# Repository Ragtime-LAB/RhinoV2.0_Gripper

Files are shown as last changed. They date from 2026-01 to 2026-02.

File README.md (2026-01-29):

# RhinoV2.0 自适应夹爪 / Adaptive Gripper



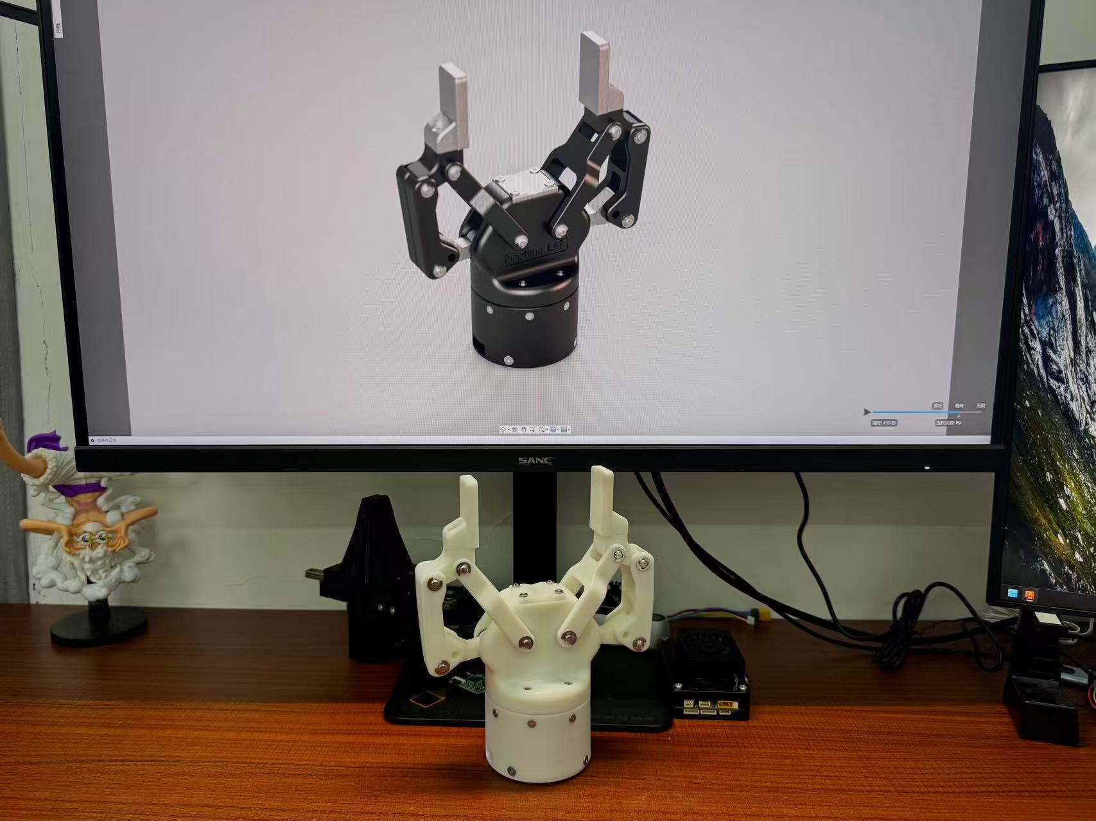
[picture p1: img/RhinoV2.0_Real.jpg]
RhinoV2.0 实物图


 

---

### 📖 项目简介

RhinoV2.0 是一款开源的自适应两指夹爪，设计灵感来源于 Robotiq 2F-85 商用夹爪。本项目旨在提供一款低成本、高性能、易于制造和组装的机械夹爪解决方案，让更多机器人爱好者、学生和个人开发者能够用上经济实惠的末端执行器。

> 💰 **成本优势**：采用 3D 打印方式制作，整套成本不超过 ¥1000，远低于商业夹爪价格！

### 🎯 项目初衷

- **降低门槛**：商业夹爪价格高昂（如 Robotiq 2F-85 售价约 ¥14,000+），我们希望让更多人用得起
- **开源共享**：所有设计文件完全开源，支持自由修改和优化
- **教育价值**：为机械工程、机器人专业的同学提供学习和参考的设计案例
- **可制造性**：采用标准件+通用加工工艺，降低制造成本
- **可扩展性**：设计模块化，便于二次开发和改进

### ✨ 主要特点

- 💰 **超低成本**：3D 打印版本整套成本 < ¥1000
- 自适应夹持，可兼容不同形状和尺寸的物体
- 欠驱动机构设计，结构紧凑
- 采用关节电机（达妙 DM4310）驱动
- 支持 FDM 3D打印或 CNC 加工
- 完整的 SolidWorks 源文件和 STEP 通用格式

### 📁 文件结构

```
RhinoV2.0_Gripper/
├── 0_Solidworks2025/          # SolidWorks 2025 源文件
│   ├── RhinoV2.0_Assembly.SLDASM   # 总装配体
│   ├── DM4310.SLDPRT               # 关节电机模型
│   └── ...                         # 所有零件模型
│
├── 1_STEP/                         # STEP 通用格式文件
│   └── RhinoV2.0_Assembly.STEP     # 完整装配体 STEP 文件
│
├── 2_Bom/                          # 物料清单与加工文件
│   ├── BOM.xlsx                    # 总物料清单
│   ├── FDM或CNC/                   # 可3D打印或 CNC 的零件
│   ├── 嘉立创钣金304或铨洲/          # 钣金件或CNC加工文件
│   ├── 铨洲三轴CNC/                 # CNC 加工文件
│   └── 丝杆及螺母/                  # 丝杆组件相关
│
├── 3_RhinoV2.0_Gripper_control/   # 夹爪控制系统代码
│   ├── gripper_ui_integrated.py    # 整合控制UI（推荐）
│   ├── motor_control_pyqt.py       # 手动控制程序
│   ├── damiao.py                   # 达妙电机控制库
│   ├── test_pressure.py            # 压力传感器测试
│   ├── requirements.txt            # Python依赖
│   └── README.md                   # 控制系统详细文档
│
├── img/                            # 项目图片
│   └── RhinoV2.0_Real.jpg          # 实物图
│
├── README.md                  # 本文件
└── LICENSE                    # GPL-3.0 开源许可证
```

### ⚙️ 硬件配置

| 项目 | 参数 |
|---|---|
| 驱动电机 | 达妙 DM4310 关节电机 |
| 夹持行程 | (待补充) |
| 最大夹持力 | (待补充) |
| 重量 | (待补充) |
| 加工方式 | FDM 3D打印 / CNC / 钣金 |

### 🚀 快速开始

#### 1. 📄 获取设计文件

- **SolidWorks 用户**：直接使用 `0_Solidworks2025/` 中的源文件进行修改
- **其他 CAD 软件**：导入 `1_STEP/RhinoV2.0_Assembly.STEP` 文件

#### 2. 🔧 零件加工

参考 `2_Bom/` 目录下的详细清单：
- 可 3D 打印零件列表
- CNC 加工图纸
- 钣金件加工文件
- 标准件采购清单（轴承、螺丝等）

> 💡 **学生党福利**：如果您觉得结构件或丝杆价格昂贵，欢迎联系我们组织拼单购买，多人一起可以降低成本！

#### 3. 🔨 组装

(详细的组装教程视频/文档即将推出)

### 🤝 贡献指南

我们欢迎任何形式的贡献：

- 🐛 报告 Bug
- 💡 提出新功能建议
- 🎨 提交设计改进
- 📝 完善文档
- 📸 分享您的制作成果

**有意向加入团队？**

如果您对这个项目充满热情，希望加入我们的团队一起开发更好的夹爪，欢迎通过上述联系方式（邮箱或微信）与我们联系！我们期待您的加入！

### ⚖️ 许可证

本项目采用 [GPL-3.0 License](LICENSE) 开源协议，主要特点：

- ✅ **允许商业使用**：您可以自由地将本项目用于商业目的
- ✅ **要求开源**：如果您基于本项目修改或衍生出新作品，必须同样以 GPL-3.0 协议开源
- ✅ **专利保护**：GPL-3.0 提供明确的专利授权保护，防止专利诉讼
- ✅ **自由使用**：您可以自由使用、修改和分发本项目

> 💡 **简单来说**：您可以商用、可以修改，但修改后的代码也必须开源！

### 🙏 致谢

- 设计灵感来源于 [Robotiq 2F-85](https://robotiq.com/products/2f85-140-adaptive-robot-gripper)
- 感谢所有为本项目做出贡献的开发者

**特别鸣谢 / Special Thanks**

- **小一** - 感谢您的赞助支持 | GitHub: [KelvinLauMiau](https://github.com/KelvinLauMiau)
贡献：为结构提出大部分思路以及外观优化以及所有研发费用的支出
- **乐乐汉堡** - 感谢您的激励和指导 | Bilibili: [乐乐汉堡](https://space.bilibili.com/435723766?spm_id_from=333.337.0.0)
贡献：作为作者的学习的榜样，并提出关键指导

### 📧 联系方式

- 👤 作者：wEch1ng（芝士榴莲肥牛）
- 🔗 前代项目：[RhinoV1.0_Gripper](https://github.com/wEch1ng/Rhino_Gripper)
- 📧 邮箱：3575868884@qq.com
- 💬 微信：xwccc12028
- 🤝 如有问题或合作意向，欢迎联系！

---

**如果这个项目对您有帮助，请给一个 Star ⭐**

---

**[回到顶部](#rhinov20-自适应夹爪)**

---



RhinoV2.0 实物图

 

---

### 📖 Introduction

RhinoV2.0 is an open-source adaptive two-finger gripper, inspired by the commercial Robotiq 2F-85 gripper. This project aims to provide a low-cost, high-performance, and easy-to-manufacture robotic gripper solution, making end-effectors accessible to more robotics enthusiasts, students, and individual developers.

> 💰 **Cost Advantage**: With 3D printing, the complete set costs less than $200, far below commercial gripper prices!

### 🎯 Project Motivation

- **Accessibility**: Commercial grippers are expensive (e.g., Robotiq 2F-85 costs around $2000+), we aim to make them affordable
- **Open Source**: All design files are fully open-source, supporting free modification and optimization
- **Educational Value**: Provides design references for mechanical engineering and robotics students
- **Manufacturability**: Uses standard parts and common manufacturing processes to reduce cost
- **Extensibility**: Modular design facilitates secondary development and improvements

### ✨ Key Features

- 💰 **Ultra-low Cost**: 3D printed version complete set < $200
- Adaptive gripping compatible with objects of various shapes and sizes
- Underactuated mechanism design with compact structure
- Joint motor (DAMIAO DM4310) driven
- Supports FDM 3D printing or CNC machining
- Complete SolidWorks source files and STEP universal format

### 📁 File Structure

```
RhinoV2.0_Gripper/
├── 0_Solidworks2025/          # SolidWorks 2025 source files
│   ├── RhinoV2.0_Assembly.SLDASM   # Main assembly
│   ├── DM4310.SLDPRT              # Joint motor model
│   └── ...                        # All part models
│
├── 1_STEP/                    # STEP universal format files
│   └── RhinoV2.0_Assembly.STEP    # Complete assembly STEP file
│
├── 2_Bom/                     # Bill of materials and manufacturing files
│   ├── BOM.xlsx                    # Total BOM list
│   ├── FDM或CNC/                   # FDM 3D printing or CNC parts
│   ├── 嘉立创钣金304或铨洲/         # Sheet metal fabrication or CNC files
│   ├── 铨洲三轴CNC/                 # CNC machining files
│   └── 丝杆及螺母/                  # Lead screw assembly related
│
├── 3_RhinoV2.0_Gripper_control/   # Gripper control system code
│   ├── gripper_ui_integrated.py    # Integrated control UI (recommended)
│   ├── motor_control_pyqt.py       # Manual control program
│   ├── damiao.py                   # DAMIAO motor control library
│   ├── test_pressure.py            # Pressure sensor test
│   ├── requirements.txt            # Python dependencies
│   └── README.md                   # Control system documentation
│
├── img/                       # Project images
│   └── RhinoV2.0_Real.jpg          # Photo of real product
│
├── README.md                  # This file
└── LICENSE                    # GPL-3.0 open source license
```

### ⚙️ Hardware Specifications

| Item | Specification |
|---|---|
| Motor | DAMIAO DM4310 Joint Motor |
| Gripping Stroke | (TBD) |
| Max Gripping Force | (TBD) |
| Weight | (TBD) |
| Manufacturing | FDM 3D printing / CNC / Sheet metal |

### 🚀 Quick Start

#### 1. 📄 Obtain Design Files

- **For SolidWorks Users**: Use source files in `0_Solidworks2025/` directly for modification
- **For Other CAD Software**: Import `1_STEP/RhinoV2.0_Assembly.STEP` file

#### 2. 🔧 Parts Manufacturing

Refer to detailed lists in `2_Bom/` directory:
- 3D printable parts list
- CNC machining drawings
- Sheet metal fabrication files
- Standard parts procurement list (bearings, screws, etc.)

> 💡 **For Students**: If you find structural parts or lead screws expensive, feel free to contact us to organize group purchases. Buying together can reduce costs significantly!

#### 3. 🔨 Assembly

(Detailed assembly tutorial video/documentation coming soon)

### 🤝 Contributing

We welcome contributions in any form:

- 🐛 Bug reports
- 💡 Feature requests
- 🎨 Design improvements
- 📝 Documentation enhancements
- 📸 Share your build

**Interested in Joining the Team?**

If you are passionate about this project and want to join our team to develop better grippers together, please feel free to contact us via email or WeChat listed above. We look forward to having you!

### ⚖️ License

This project is licensed under the [GPL-3.0 License](LICENSE). Key features:

- ✅ **Commercial Use Allowed**: You are free to use this project for commercial purposes
- ✅ **Copyleft Required**: If you modify or create derivative works based on this project, you must release them under GPL-3.0 as well
- ✅ **Patent Protection**: GPL-3.0 provides explicit patent license protection to prevent patent litigation
- ✅ **Freedom to Use**: You are free to use, modify, and distribute this project

> 💡 **In Short**: Commercial use is allowed, modifications are allowed, but modified code must also be open source!

### 🙏 Acknowledgments

- Design inspired by [Robotiq 2F-85](https://robotiq.com/products/2f85-140-adaptive-robot-gripper)
- Thanks to all developers who contributed to this project

**Special Thanks**

- **小一 (Xiao Yi)** - Thank you for your sponsorship | GitHub: [KelvinLauMiau](https://github.com/KelvinLauMiau)
  - Contribution: Proposed most of the structural design concepts, appearance optimization, and covered all R&D expenses
- **乐乐汉堡 (Lele Hamburger)** - Thank you for your motivation and guidance | Bilibili: [乐乐汉堡](https://space.bilibili.com/435723766?spm_id_from=333.337.0.0)
  - Contribution: Served as the author's role model and provided key guidance

### 📧 Contact

- 👤 Author: wEch1ng（芝士榴莲肥牛）
- 🔗 Previous Project: [RhinoV1.0_Gripper](https://github.com/wEch1ng/Rhino_Gripper) 
- 📧 Email: 3575868884@qq.com
- 💬 WeChat: xwccc12028
- 🤝 Feel free to contact for any questions or collaboration!

---

**If this project helps you, please give it a Star ⭐**

---

**[Back to Top](#rhinov20-自适应夹爪)**

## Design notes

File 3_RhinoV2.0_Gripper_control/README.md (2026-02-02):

# RhinoV2.0 夹爪控制系统

本项目是基于达妙电机和压力传感器的智能夹爪控制系统，支持手动控制和PID闭环控制两种模式。

---

## 目录

- [硬件清单](#硬件清单)
- [环境安装](#环境安装)
- [快速开始](#快速开始)
- [文件结构](#文件结构)
- [主要程序说明](#主要程序说明)
- [配置说明](#配置说明)
- [常见问题](#常见问题)
- [开发说明](#开发说明)
- [安全注意事项](#安全注意事项)

---

## 硬件清单

### 必需硬件

#### 1. 达妙电机
- **型号**：DM4310（或 DM4340、DM6006 等）
- **额定力矩**：4.3 N·m (DM4310)
- **控制模式**：MIT模式、位置速度模式、速度模式
- **通信接口**：CAN总线
- **供电**：24V DC
- **厂商**：达妙科技
- **用途**：夹爪驱动执行器

#### 2. USB-CAN适配器
- **型号**：DM-FDCAN
- **接口**：USB 2.0
- **CAN协议**：CAN 2.0 / CAN-FD
- **波特率**：可配置（默认 1Mbps）
- **厂商**：达妙科技
- **用途**：电脑与电机CAN总线通信

#### 3. 6x6阵列压力传感器（仅作参考）
- **型号**：6x6阵列压力传感器（36点）
- **厂商**：深圳力感科技
- **类型**：电阻式力敏触觉传感器 (FSR)
- **阵列规格**：6×6 = 36个传感点
- **单点尺寸**：2.5mm × 2.5mm
- **单点面积**：6.25 mm²
- **通信接口**：串口 (UART)
- **波特率**：460800
- **数据格式**：自定义协议（帧头 0xFF66，78字节/帧）
- **应用场景**：机器人手指抓握力识别、触觉反馈
- **购买链接**：
【淘宝】退货运费险 https://e.tb.cn/h.7qFeOVKt2sKIyvf?tk=kPtyU7QJ8po MF937 「原厂人形机器人手指识别抓握力大小电阻式力敏多点触觉传感器FSR」
点击链接直接打开 或者 淘宝搜索直接打开

### 可选硬件

- **电源**：24V DC电源适配器（电机供电）
- **CAN终端电阻**：120Ω（CAN总线两端）
- **连接线缆**：
  - USB数据线（连接USB-CAN适配器）
  - CAN总线线缆
  - 串口线（连接压力传感器）

### 硬件连接示意

```
电脑 ──USB── USB-CAN适配器 ──CAN总线── 达妙电机
 │
 └──串口── 压力传感器
```

---

## 环境安装

### 系统要求

- **操作系统**：Linux (推荐 Ubuntu 18.04+)
- **Python 版本**：Python 3.8+
- **硬件要求**：
  - USB-CAN适配器（达妙 DM-FDCAN）
  - 达妙电机（DM4310 或其他型号）
  - 6x6阵列压力传感器（深圳力感科技）

### 安装步骤

#### 1. 克隆或下载项目

```bash
cd /home/wech1ng/Project/
# 如果已有项目，跳过此步
```

#### 2. 安装Python依赖

```bash
cd RhinoV2.0_Gripper_control

# 方法1：使用 requirements.txt（推荐）
pip3 install -r requirements.txt

# 方法2：手动安装
pip3 install PyQt5>=5.15.0
pip3 install numpy>=1.19.0
pip3 install matplotlib>=3.3.0
pip3 install pyserial>=3.5
pip3 install pyusb>=1.2.0
```

#### 3. 配置USB设备权限

```bash
# 添加当前用户到 dialout 组（串口权限）
sudo usermod -a -G dialout $USER

# 设置USB设备权限（USB-CAN适配器）
sudo chmod 666 /dev/bus/usb/*/*

# 注意：需要重新登录或重启才能生效
```

#### 4. 验证安装

```bash
# 检查Python版本
python3 --version

# 检查依赖库
python3 -c "import PyQt5, numpy, matplotlib, serial, usb; print('所有依赖库已安装')"

# 检查USB-CAN设备
python3 dev_sn.py
```

**预期输出：**
```
Found DM-FDCAN, device-id: device:3,21 SN: 818F9E6ACF42F4147B2EE0FE9382AF11
```

---

## 快速开始

### 1. 硬件连接

#### 电机连接
1. 连接USB-CAN适配器到电脑USB口
2. 连接达妙电机到CAN总线
3. 确保电机供电正常（24V）

#### 传感器连接
1. 连接压力传感器到串口（通常是 `/dev/ttyUSB1` 或 `/dev/ttyACM0`）
2. 确认波特率为 460800

**传感器规格：**
- **型号**：6x6阵列压力传感器（36点）
- **厂商**：深圳力感科技
- **类型**：电阻式力敏触觉传感器 (FSR)
- **单点尺寸**：2.5mm × 2.5mm
- **通信接口**：串口 (UART)
- **波特率**：460800
- **应用场景**：机器人手指抓握力识别、触觉反馈

> **购买参考**：淘宝搜索"人形机器人手指识别抓握力大小电阻式力敏多点触觉传感器FSR"

### 2. 读取设备序列号（重要）

每个USB-CAN适配器都有唯一的设备序列号（SN），需要先读取并配置到程序中。

```bash
# 运行设备序列号读取工具
python3 dev_sn.py
```

**输出示例：**
```
Found DM-FDCAN, device-id: device:3,21 SN: 818F9E6ACF42F4147B2EE0FE9382AF11
```

记录下这个 **SN码**：`818F9E6ACF42F4147B2EE0FE9382AF11`

### 3. 修改程序中的设备码

找到程序中的这一行（通常在主函数或初始化部分）：

```python
self.control = Motor_Control(1000000, 5000000,
                            "818F9E6ACF42F4147B2EE0FE9382AF11",  # ← 修改这里
                            init_data)
```

**将SN码替换为你的设备码。**

#### 需要修改的文件：

1. **gripper_ui_integrated.py**（推荐使用）
   - 位置：`init_hardware()` 函数中，约第667行
   - 搜索：`Motor_Control(1000000, 5000000,`

2. **motor_control_pyqt.py**
   - 位置：`init_motor()` 函数中，约第295行

3. **gripper_control_with_visualization.py**
   - 位置：`if __name__ == "__main__":` 部分

#### 修改示例：

**修改前：**
```python
with Motor_Control(1000000, 5000000, "818F9E6ACF42F4147B2EE0FE9382AF11", init_data1) as control:
```

**修改后（假设你的SN是 `AA96DF2EC013B46B1BE4613798544085`）：**
```python
with Motor_Control(1000000, 5000000, "AA96DF2EC013B46B1BE4613798544085", init_data1) as control:
```

### 4. 检查串口设备

```bash
# 查看可用串口
ls -l /dev/ttyUSB* /dev/ttyACM*
```

**输出示例：**
```
/dev/ttyUSB1  # 压力传感器
/dev/ttyACM0  # 其他设备
```

如果传感器不在 `/dev/ttyUSB1`，需要修改程序中的串口配置：

```python
# 在程序开头找到这一行（约第33行）
SERIAL_PORT = '/dev/ttyUSB1'  # 修改为实际串口
```

### 5. 运行程序

#### 推荐：使用整合UI程序

```bash
python3 gripper_ui_integrated.py
```

**操作步骤：**
1. 程序启动，自动初始化电机和传感器
2. 点击 **"使能电机"** 按钮
3. 选择控制模式：
   - **手动控制**：切换到"手动控制"标签页，点击"打开"或"闭合"
   - **PID控制**：切换到"PID控制+可视化"标签页，设置参数后点击"开始PID控制"
4. 使用完毕后点击 **"失能电机"** 或直接关闭窗口

#### 其他程序

```bash
# 手动控制UI
python3 motor_control_pyqt.py

# 压力传感器测试（含可视化）
python3 test_pressure.py

# PID控制+可视化（按'q'退出）
python3 gripper_control_with_visualization.py
```

---

## 文件结构

```
RhinoV2.0_Gripper_control/
├── README.md                                    # 本文档
├── requirements.txt                             # Python依赖库列表
├── dm_README.md                                 # 达妙电机原始文档
├── dev_sn.py                                    # 设备序列号读取工具
│
├── 核心库
│   ├── damiao.py                                # 达妙电机控制库（核心）
│   └── src/                                     # 达妙电机底层驱动
│       ├── __init__.py
│       └── usb_class.*.so                       # USB-CAN通信库（编译后的二进制文件）
│
├── 压力传感器程序
│   └── test_pressure.py                         # 压力传感器测试程序（含可视化）
│
├── 单功能程序
│   └── motor_control_pyqt.py                    # 电机手动控制UI
│
├── 整合程序（推荐使用）
│   └── gripper_ui_integrated.py                 # 整合UI（推荐）★
│
└── docs/                                        # 文档图片资源
    ├── catkin.png
    ├── dev.png
    └── motor_control.png
```

---

## 主要程序说明

### 核心库

#### `damiao.py`
- **作用**：达妙电机控制核心库
- **功能**：
  - 电机初始化和配置
  - MIT模式、位置速度模式、速度模式控制
  - 电机使能/失能
  - 参数读写
  - CAN通信管理

#### `dev_sn.py`
- **作用**：读取USB-CAN适配器设备序列号
- **功能**：枚举USB设备并显示设备SN码
- **使用**：`python3 dev_sn.py`

#### `src/usb_class.*.so`
- **作用**：USB-CAN适配器通信库（编译后的二进制文件）
- **功能**：USB设备枚举、CAN帧收发、波特率配置
- **说明**：针对不同平台和Python版本的预编译库

### 压力传感器程序

#### `test_pressure.py`
- **作用**：压力传感器数据采集、解析和可视化
- **功能**：
  - 串口通信
  - 数据帧解析
  - 压力校准
  - AD值转换为压强/压力
  - 6x6传感器阵列热力图显示
  - 实时数据可视化
  - 统计信息显示

### 单功能程序

#### `motor_control_pyqt.py`
- **作用**：电机手动控制GUI程序
- **功能**：
  - 打开/闭合按钮控制
  - 力矩值设置
  - 使能/失能管理
- **使用场景**：手动操作夹爪

### 整合程序（推荐）

#### `gripper_ui_integrated.py` ★★★
- **作用**：完整的夹爪控制系统（推荐使用）
- **功能**：
  - **标签页1：手动控制**
    - 打开/闭合按钮
    - 力矩值调节
  - **标签页2：PID控制 + 可视化**
    - 左侧：PID参数设置、状态显示、控制按钮
    - 右侧：6x6传感器热力图实时显示
  - 使能/失能管理
  - 资源自动清理
- **优势**：
  - 界面友好
  - 功能完整
  - 性能优化，无卡顿
  - 适合实际使用

---

## 配置说明

### 电机配置

在程序中找到电机初始化部分：

```python
init_data1 = []
canid1 = 0x01  # 电机CAN ID
mstid1 = 0x11  # 主站ID

init_data1.append(DmActData(
    motorType=DM_Motor_Type.DM4310,  # 电机型号
    mode=Control_Mode.MIT_MODE,       # 控制模式
    can_id=canid1,
    mst_id=mstid1))
```

**可配置项：**
- `canid1`：电机的CAN ID（默认 0x01）
- `mstid1`：主站ID（默认 0x11）
- `motorType`：电机型号（DM4310, DM4340, DM6006等）
- `mode`：控制模式（MIT_MODE, POS_VEL_MODE, VEL_MODE）

### 传感器配置

#### 基本配置

```python
SERIAL_PORT = '/dev/ttyUSB1'  # 串口设备
BAUDRATE = 460800              # 波特率（固定，不可修改）
```

#### 传感器参数

```python
# 传感器阵列规格
SENSOR_COUNT = 36              # 传感器点数（6x6）
GRID_SIZE = 6                  # 网格尺寸
SENSOR_AREA_MM2 = 2.5 * 2.5   # 单点面积 (mm²)
SENSOR_AREA_M2 = 6.25e-6      # 单点面积 (m²)

# 数据帧格式
HEADER = b'\xFF\x66'           # 帧头
FRAME_SIZE = 78                # 帧大小（字节）
# 帧结构：帧头(2) + 保留(2) + AD值(72) + 校验和(2)
```

#### 校准参数

每个传感器点都有独立的校准参数（斜率k和截距b），用于将AD值转换为压强：

```python
# 压强计算公式
pressure_kPa = k * ad_value + b

# 压力计算公式
pressure_N = pressure_kPa * 1000 * sensor_area_m2
```

校准参数已内置在程序中（`PressureSensorCalibration` 类），无需手动配置。

#### 偏移校准

PID控制模式下，程序会自动进行偏移校准（零点校准）：
- 采集10帧无负载数据
- 计算每个传感器的平均偏移值
- 后续测量值减去偏移值

**注意**：开始PID控制前，确保传感器表面无外力。

### PID参数

在UI中可以实时调整，或在代码中修改默认值：

```python
self.target_force = 0.15  # 目标夹持力 (N)
kp = 2.0                  # 比例系数
ki = 0.1                  # 积分系数
kd = 0.0                  # 微分系数
```

---

## 常见问题

### 1. 找不到USB-CAN设备

**错误信息：**
```
No DM-FDCAN device found
```

**解决方法：**
- 检查USB-CAN适配器是否连接
- 检查USB线缆
- 运行 `lsusb` 查看设备是否被识别
- 检查设备权限：`sudo chmod 666 /dev/bus/usb/*/*`

### 2. 设备序列号不匹配

**错误信息：**
```
Device SN mismatch
```

**解决方法：**
- 使用 `python3 dev_sn.py` 读取正确的SN码
- 修改程序中的SN码为实际设备的SN码

### 3. 串口连接失败

**错误信息：**
```
could not open port /dev/ttyUSB0: [Errno 2] 没有那个文件或目录
```

**解决方法：**
- 运行 `ls -l /dev/ttyUSB* /dev/ttyACM*` 查看可用串口
- 修改程序中的 `SERIAL_PORT` 为实际串口
- 检查串口权限：`sudo chmod 666 /dev/ttyUSB1`
- 将用户添加到 dialout 组：`sudo usermod -a -G dialout $USER`（需要重新登录）

### 4. 电机不响应

**可能原因：**
- 电机未使能：点击"使能电机"按钮
- CAN ID配置错误：检查电机实际ID
- 电机供电问题：检查电源
- CAN总线连接问题：检查线缆和终端电阻

### 5. 传感器数据异常

**可能原因：**
- 波特率不匹配：确认为 460800
- 串口设备错误：检查实际串口
- 传感器供电问题
- 数据线接触不良

### 6. 程序无法退出

**解决方法：**
- 在可视化窗口按 'q' 键
- 关闭可视化窗口
- 终端按 Ctrl+C
- 如果卡住，使用 `kill -9 <pid>`

### 7. 依赖库安装失败

**PyQt5 安装失败：**
```bash
# Ubuntu/Debian
sudo apt-get install python3-pyqt5

# 或使用国内镜像
pip3 install -i https://pypi.tuna.tsinghua.edu.cn/simple PyQt5
```

**pyusb 权限问题：**
```bash
# 创建udev规则
sudo nano /etc/udev/rules.d/99-usb.rules

# 添加以下内容：
SUBSYSTEM=="usb", MODE="0666"

# 重新加载规则
sudo udevadm control --reload-rules
```

---

## 开发说明

### 依赖库说明

| 库名 | 版本要求 | 用途 |
|---|---|---|
| PyQt5 | >=5.15.0 | GUI界面框架 |
| numpy | >=1.19.0 | 数值计算 |
| matplotlib | >=3.3.0 | 数据可视化 |
| pyserial | >=3.5 | 串口通信 |
| pyusb | >=1.2.0 | USB设备通信 |

### 添加新电机

在 `damiao.py` 中添加电机配置：

```python
init_data.append(DmActData(
    motorType=DM_Motor_Type.DM4310,
    mode=Control_Mode.MIT_MODE,
    can_id=0x02,  # 新电机ID
    mst_id=0x12))
```

### 修改控制周期

```python
cycle_time = 0.01  # 10ms控制周期（100Hz）
```

### 调试模式

在程序中添加调试输出：

```python
print(f"当前力: {current_force:.3f}N")
print(f"电机输出: {motor_output:.3f}N·m")
```

---

## 安全注意事项

### 1. 首次使用
- 先在无负载情况下测试
- 从小力矩开始测试（建议从0.05 N·m开始）
- 确保急停措施可用
- 熟悉"失能电机"按钮位置

### 2. 运行时
- 确保夹爪周围无障碍物
- 不要超过电机额定力矩（DM4310: 4.3 N·m）
- 注意观察电机温度
- 异常情况立即点击"失能电机"

### 3. 退出程序
- 优先使用"失能电机"按钮
- 确保电机已停止再断电
- 不要强制杀死进程（避免电机处于使能状态）

### 4. 维护保养
- 定期检查线缆连接
- 清洁传感器表面
- 检查CAN总线终端电阻
- 记录异常情况和参数

---

## 技术支持

- **达妙电机文档**：查看 `dm_README.md`
- **问题反馈**：提交 Issue
- **项目维护**：wech1ng

---

## 更新日志

### 2026-01-30
- 添加 requirements.txt 依赖管理
- 重新组织 README 结构
- 将环境安装说明移至最前
- 添加硬件清单章节
- 详细说明传感器规格（深圳力感科技 6x6阵列压力传感器）
- 更新传感器配置说明（校准参数、偏移校准）
- 更新文件结构说明
- 添加更详细的故障排除指南

### 2026-01-29
- 创建整合UI程序
- 修复可视化卡顿问题
- 优化界面布局
- 添加详细文档

### 2026-01-28
- 初始版本
- 实现基本控制功能

---

## 许可证

本项目仅供学习和研究使用。

---

## 致谢

感谢达妙科技提供的电机控制库和技术支持。

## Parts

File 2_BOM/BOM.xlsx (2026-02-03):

序号 | 商品名称 | 数量（件） | 样图 | 链接 | 型号 | 备注
1 | 转子丝杆传动件 | 1 | =DISPIMG("ID_D85C9EF270594632B9A0DBE77F256DBB",1) | 铨洲cnc
2 | 螺母连杆 | 4 | =DISPIMG("ID_53E51DEE8413422F8BA9F6DD8F4D4245",1) | 嘉立创钣金或铨洲 |  | 强度可能不太够，尽量选择钣金不锈钢304
3 | 底盖 | 1 | =DISPIMG("ID_C2CFE7C563E245EBB2AF113D6717863B",1) | 3D打印（PETG）或cnc |  | 不建议光固化，光固化热熔螺母融进去效果不好
4 | 电机外壳 | 1 | =DISPIMG("ID_A5B5F48B6D204A95B8B49B51ECD6EAF2",1)
5 | 外壳 | 1 | =DISPIMG("ID_2EE8B1F094224D8885081A4D2FC359B4",1)
6 | 主动杆 | 2 | =DISPIMG("ID_9364E3A5722A47A9BB5890CC2D9BE2C0",1)
7 | 欠驱动杆 | 2 | =DISPIMG("ID_D4C94E9C0B334A51A478276F795C42CE",1)
8 | 镜向欠驱动杆 | 2 | =DISPIMG("ID_43B7016F659E42DB9FC4A94C7BE16562",1)
9 | 手指连杆 | 2 | =DISPIMG("ID_7D4063E113464638AAB922C7138CBA66",1)
10 | 从动杆 | 2 | =DISPIMG("ID_E20711412A814922BF68C3C97D4D4620",1)
11 | 手指 | 2 | =DISPIMG("ID_6E4AF7B5A60A4C0FA7C783F346385AF9",1)
12 | 挡盖 | 1 | =DISPIMG("ID_361A7F5A95F446DE94E43574F014F5B0",1)
13 | 丝杆 | 1 | =DISPIMG("ID_1B7BDAEF3B8D442F866BCCA2B0897209",1) | 淘宝丝杆定制
14 | 丝杆螺母 | 1 | =DISPIMG("ID_B9D62EAD9A464CA7B64FE238510E8EF6",1)
15
16 | 小法兰轴承 | 4 | =DISPIMG("ID_5C7F520956984AD390BF878185608799",1) | https://item.taobao.com/item.htm?id=627537372468 | MF85ZZ (5*8*9.2*0.6*2.5)
17 | 法兰轴承 | 4 | =DISPIMG("ID_32AC1279CC114DAEB074610FFA6266D3",1) |  | MF128ZZ(8*12*13.6*0.8*3.5)
18 | 轴承 | 1 | =DISPIMG("ID_00C90E8FDB5A48B48A59E2B696220C7E",1) | https://detail.tmall.com/item.htm?id=735576032715 | 6*15*5带密封【德国级】
19 | 双头带槽销轴卡簧销 | 6 | =DISPIMG("ID_E35C70DA79CA42FBAC47AA37779D90FD",1) | https://detail.tmall.com/item.htm?id=617648776883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 | M5*30
20 |  | 2 |  |  | M5*45
21 | 对锁螺丝 | 4 | =DISPIMG("ID_5FBD058D9371446E9344BDD86CF29D48",1) | https://detail.tmall.com/item.htm?id=738916254976 | M2*14(20套)
22 | 扭簧 | 2 | =DISPIMG("ID_09360DC4601A4C6B888F223D5A336423",1) | https://detail.tmall.com/item.htm?id=774983364150 | 线经1.2毫米（10个） 备注：线径*外径*圈数*角度*左右 | 备注：线径1.2 外径7.5 圈数5 角度180 一包左旋一包右旋
23
24 | 螺丝：
25 | M5*6杯头
26 | M3*6杯头
27 | M3*5杯头
28 | M2.5*3扁平头
29 | M3*6沉头
30
31 | 电机：
32 | DM4310

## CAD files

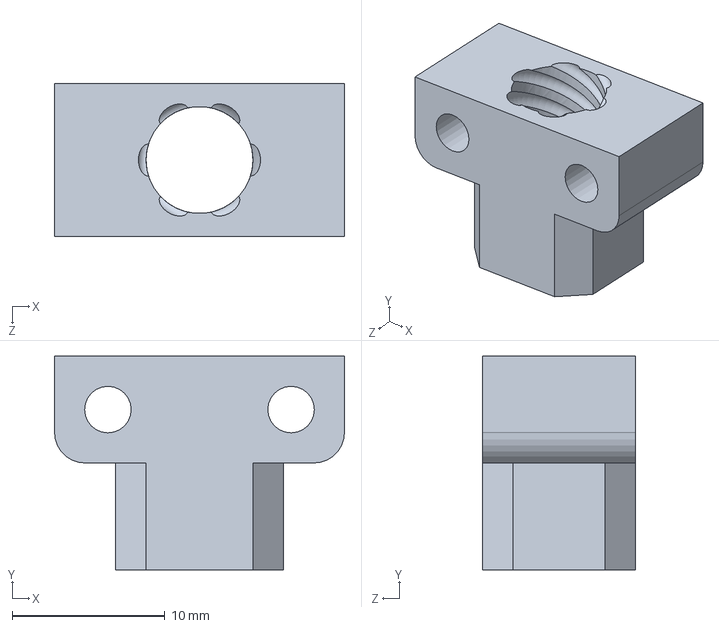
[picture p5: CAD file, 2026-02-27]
0_Solidworks2025/丝杆螺母.SLDPRT
19.0 x 14.0 x 10.0 mm

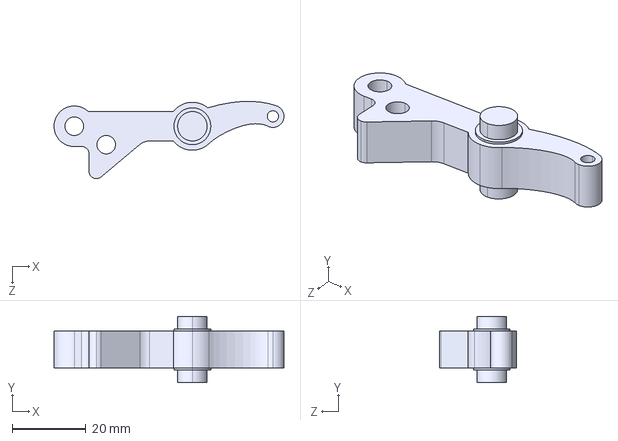
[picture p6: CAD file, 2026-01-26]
2_BOM/FDM或CNC/镜向主动杆.STEP
62.3 x 18.0 x 20.9 mm

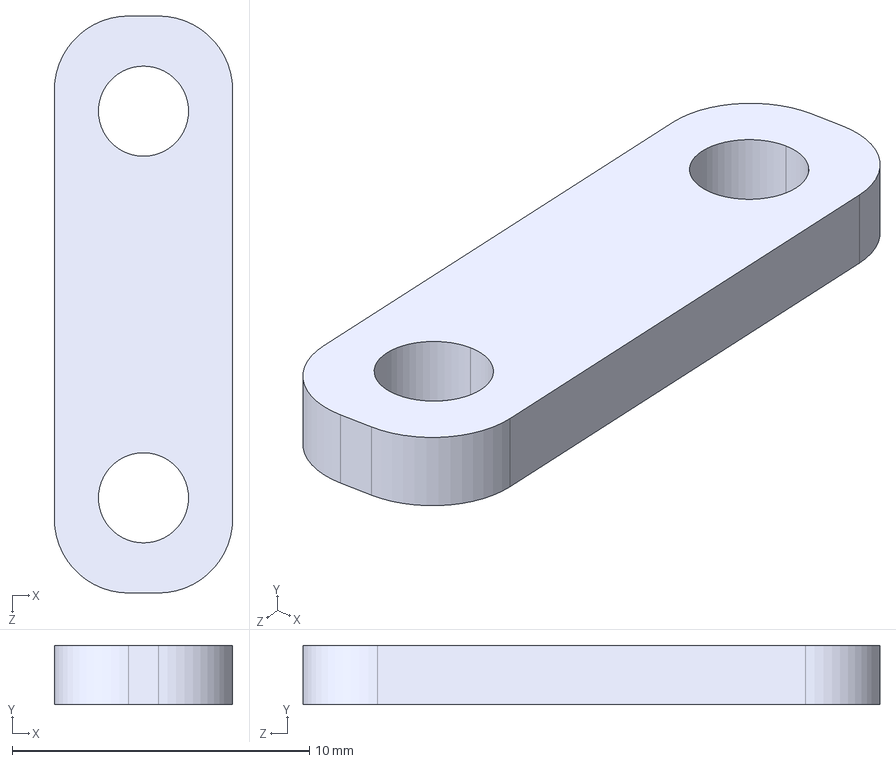
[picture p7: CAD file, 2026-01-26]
2_BOM/嘉立创钣金304或铨洲/螺母连杆.STEP
6.00 x 2.00 x 19.4 mm

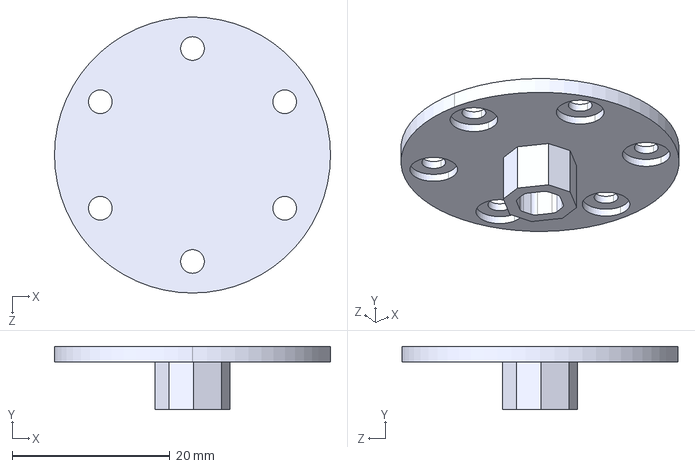
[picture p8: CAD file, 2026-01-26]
2_BOM/铨洲三轴CNC/转子丝杆传动件.STEP
35.0 x 8.00 x 35.0 mm

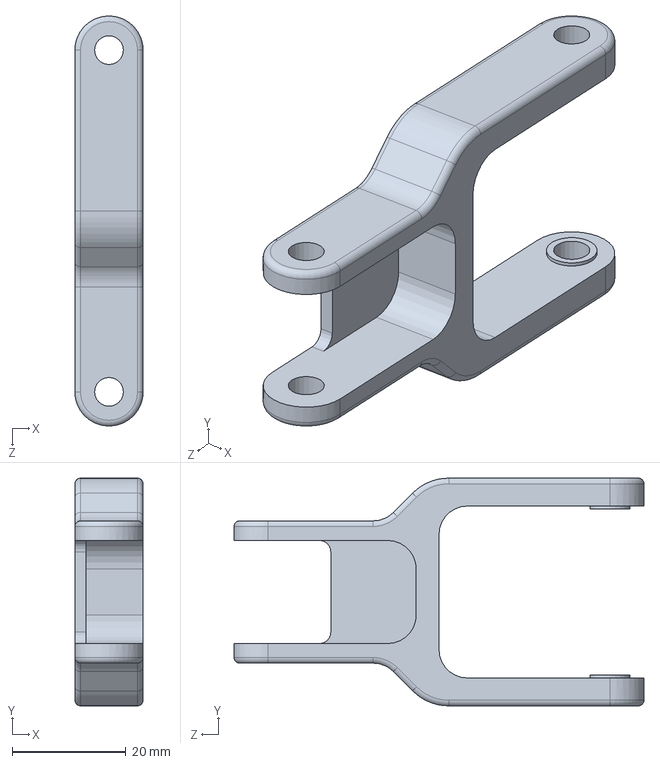
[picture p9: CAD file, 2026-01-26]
0_Solidworks2025/镜向从动杆.SLDPRT
12.0 x 40.0 x 72.0 mm

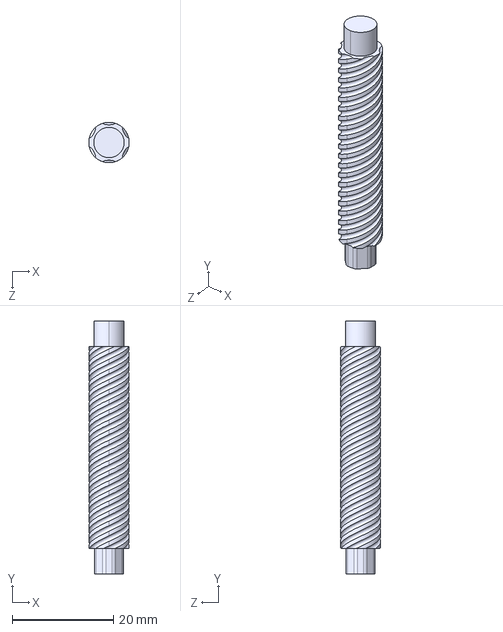
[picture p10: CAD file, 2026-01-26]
2_BOM/丝杆及螺母/丝杆.STEP
8.00 x 50.0 x 8.00 mm

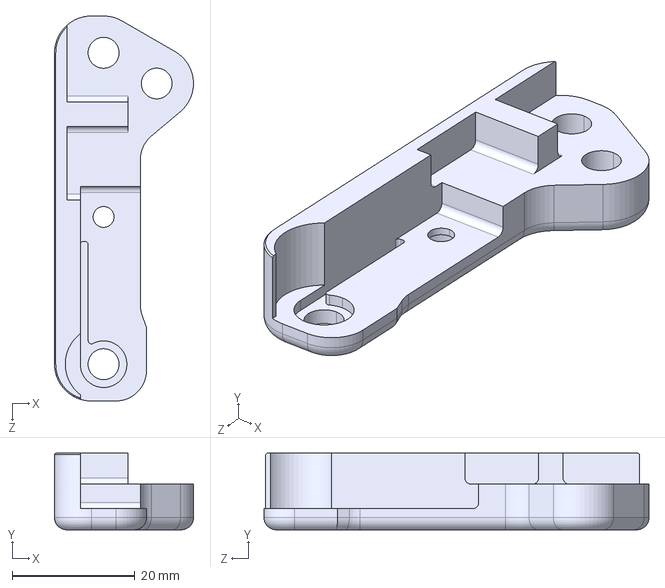
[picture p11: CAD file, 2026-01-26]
2_BOM/FDM或CNC/镜向欠驱动杆.STEP
22.7 x 12.5 x 62.8 mm

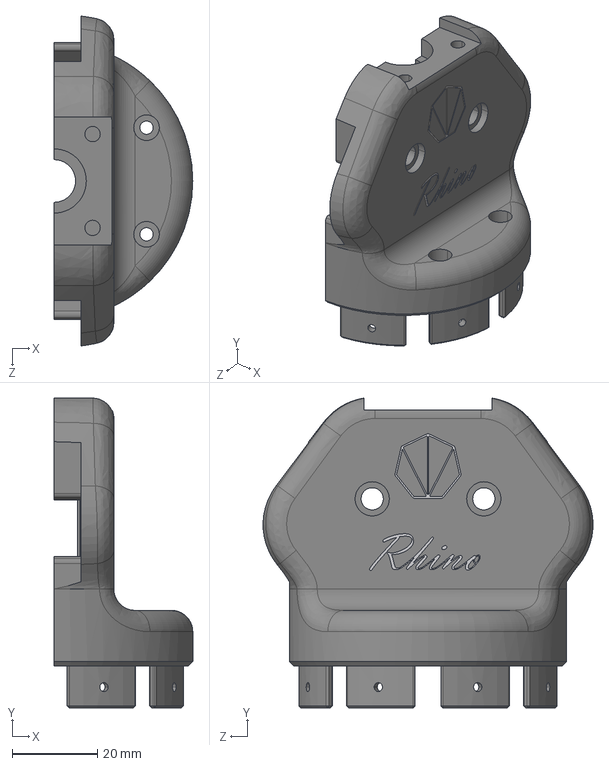
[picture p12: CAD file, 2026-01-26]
2_BOM/FDM或CNC/外壳.STEP
32.5 x 72.7 x 77.4 mm

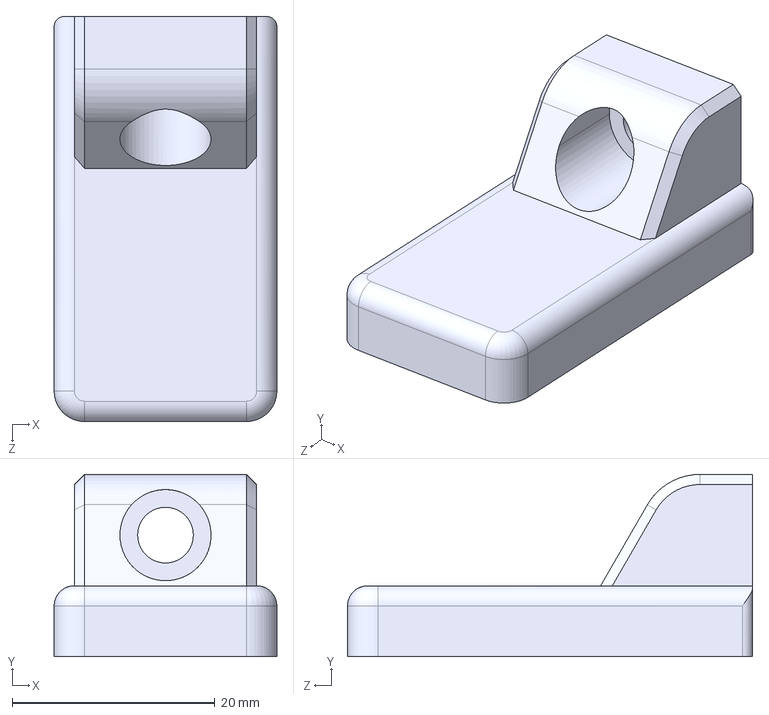
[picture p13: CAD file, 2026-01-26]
2_BOM/FDM或CNC/镜向手指.STEP
22.0 x 18.0 x 40.0 mm

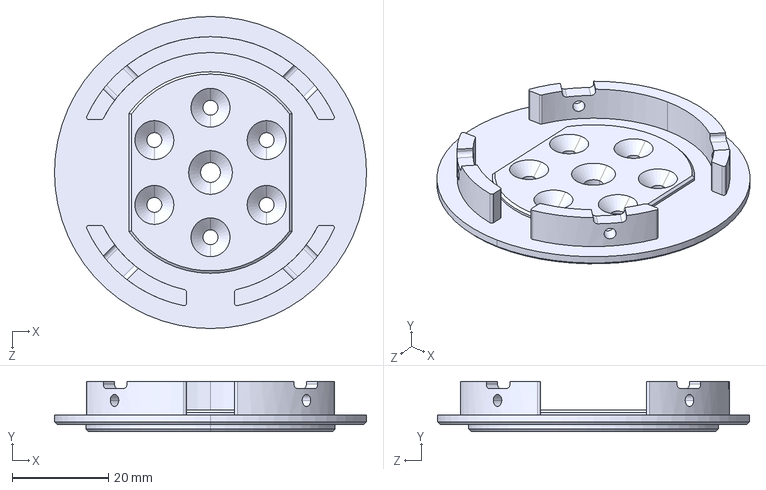
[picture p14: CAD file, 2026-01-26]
2_BOM/FDM或CNC/底盖.STEP
65.0 x 10.4 x 65.0 mm

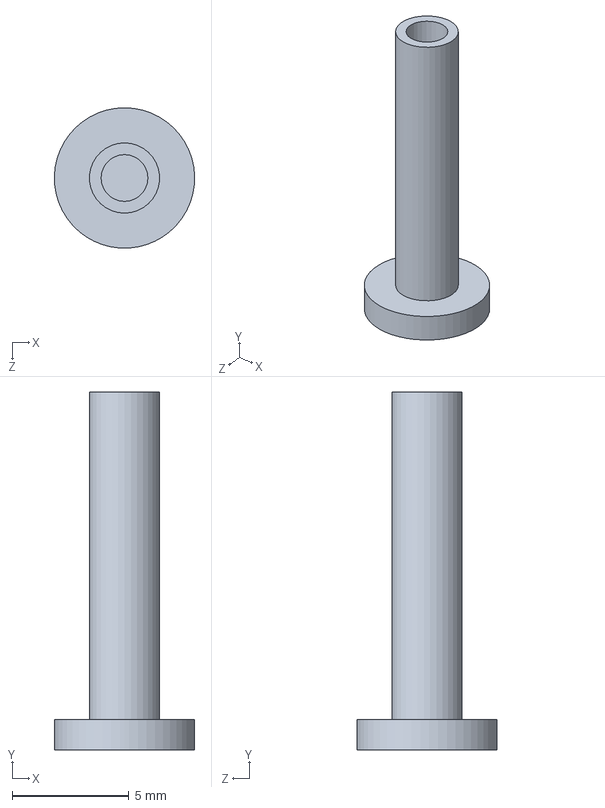
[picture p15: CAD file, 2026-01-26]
0_Solidworks2025/对锁螺丝M2_14长.SLDPRT
6.00 x 15.3 x 6.00 mm

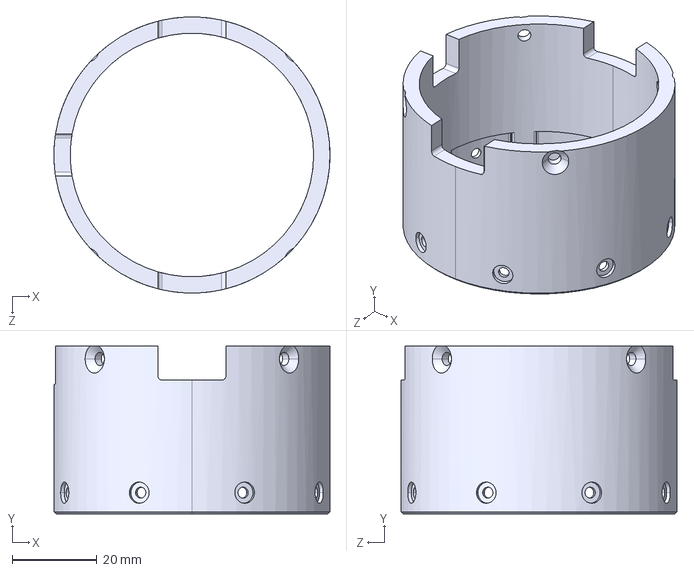
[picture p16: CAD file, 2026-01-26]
2_BOM/FDM或CNC/电机外壳.STEP
65.0 x 39.5 x 65.0 mm

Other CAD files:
2_BOM/丝杆及螺母/丝杆螺母.STEP
2_BOM/FDM或CNC/镜向从动杆.STEP
0_Solidworks2025/镜向螺母连杆.SLDPRT
0_Solidworks2025/丝杆.SLDPRT
0_Solidworks2025/欠驱动杆-镜像.SLDPRT
2_BOM/FDM或CNC/镜向欠驱动杆-镜像.STEP
0_Solidworks2025/M2.5_3扁平头.SLDPRT
0_Solidworks2025/M3_5.SLDPRT
0_Solidworks2025/M3_6.SLDPRT
0_Solidworks2025/M3_6沉头.SLDPRT
0_Solidworks2025/M5_6.SLDPRT
0_Solidworks2025/主动杆.SLDPRT
0_Solidworks2025/从动杆.SLDPRT
0_Solidworks2025/卡簧-4mm.SLDPRT
0_Solidworks2025/双头卡簧销轴m5-30.SLDPRT
0_Solidworks2025/双头卡簧销轴m5-45.SLDPRT
0_Solidworks2025/外壳.SLDPRT
0_Solidworks2025/对锁螺丝M2_14短.SLDPRT
0_Solidworks2025/底盖.SLDPRT
0_Solidworks2025/手指.SLDPRT
0_Solidworks2025/手指连杆.SLDPRT
0_Solidworks2025/挡盖.SLDPRT
0_Solidworks2025/欠驱动杆.SLDPRT
0_Solidworks2025/法兰轴承5_8_9.2_0.6_2.5.SLDPRT
0_Solidworks2025/法兰轴承8_12_13.6_0.8_3.5.SLDPRT
0_Solidworks2025/电机外壳.SLDPRT
0_Solidworks2025/螺母连杆.SLDPRT
0_Solidworks2025/转子丝杆传动件.SLDPRT
0_Solidworks2025/轴承5_15_5.SLDPRT
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

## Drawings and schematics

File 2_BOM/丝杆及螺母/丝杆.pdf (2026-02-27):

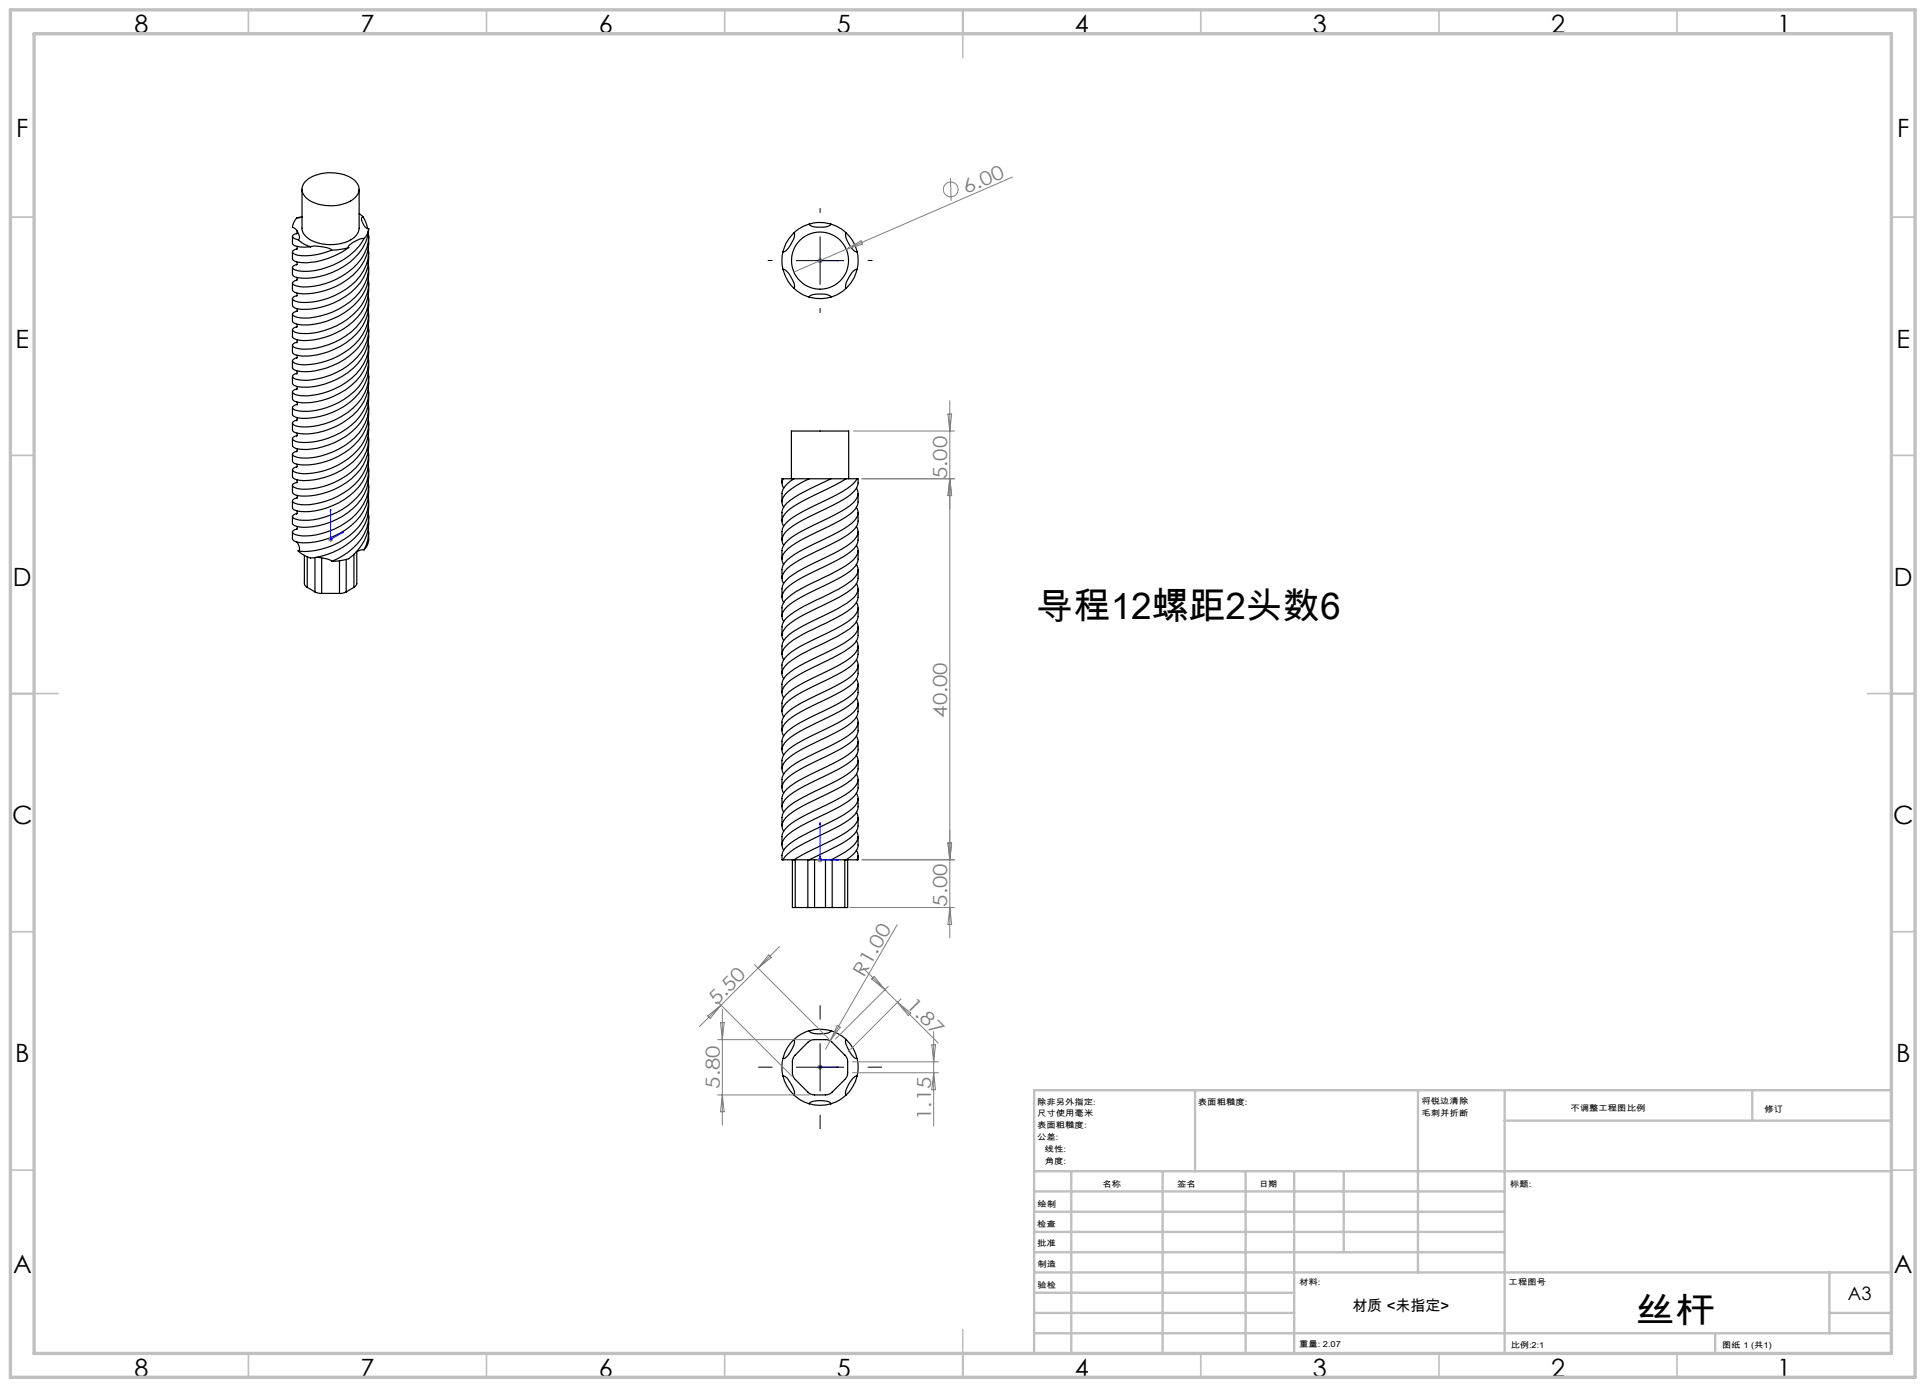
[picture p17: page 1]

绘制
检查
批准

制造
验检 | | | | 材料: | 工程图号 丝杆 | A3 材质 <未指定>

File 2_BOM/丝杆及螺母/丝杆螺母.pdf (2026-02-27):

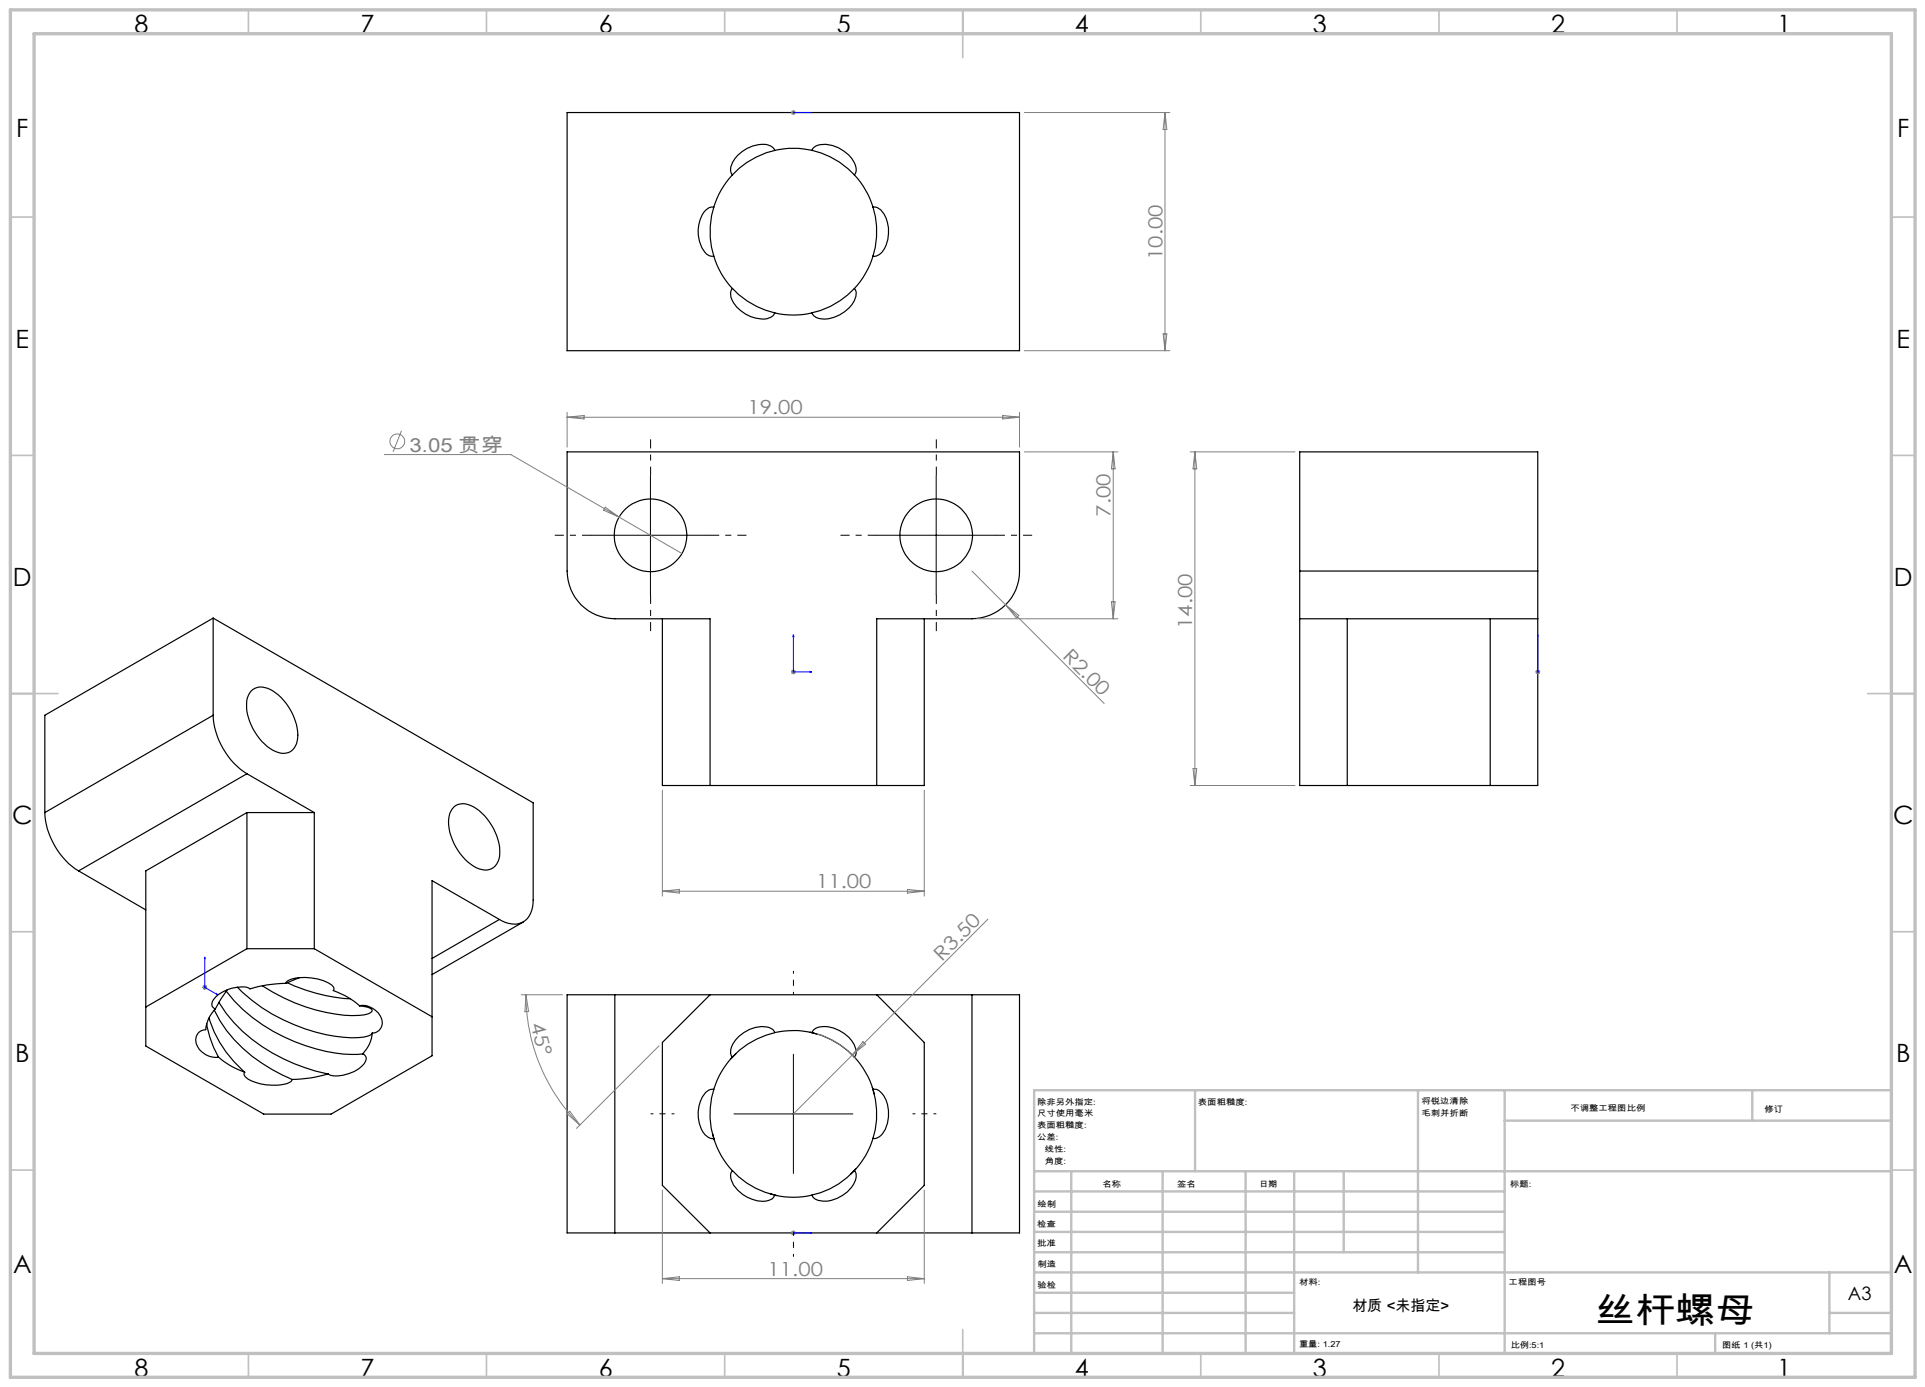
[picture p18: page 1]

绘制
检查

制造
验检 | 材料: | 工程图号 丝杆螺母 | A3 材质 <未指定>

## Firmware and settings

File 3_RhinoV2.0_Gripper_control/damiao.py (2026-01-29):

from src import usb_class,can_value_type
from enum import IntEnum
import time
import struct
import sys
from typing import Optional
import threading
import signal
from dataclasses import dataclass
from typing import List

class DM_Motor_Type(IntEnum):
    DM3507 = 0
    DM4310 = 1
    DM4310_48V = 2
    DM4340 = 3
    DM4340_48V = 4
    DM6006 = 5
    DM6248 = 6
    DM8006 = 7
    DM8009 = 8
    DM10010L = 9
    DM10010 = 10
    DMH3510 = 11
    DMH6215 = 12
    DMS3519 = 13
    DMG6220 = 14
    Num_Of_Motor = 15

class Control_Mode(IntEnum):
    MIT_MODE = 0x000
    POS_VEL_MODE = 0x100
    VEL_MODE = 0x200
    POS_FORCE_MODE = 0x300

class Control_Mode_Code(IntEnum):
    MIT = 1
    POS_VEL = 2
    VEL = 3
    POS_FORCE = 4

@dataclass
class DmActData:
    motorType: DM_Motor_Type  # 是哪款电机
    mode: Control_Mode        # 电机处于哪种控制模式
    can_id: int
    mst_id: int

class DM_REG(IntEnum):
    UV_Value = 0
    KT_Value = 1
    OT_Value = 2
    OC_Value = 3
    ACC = 4
    DEC = 5
    MAX_SPD = 6
    MST_ID = 7
    ESC_ID = 8
    TIMEOUT = 9
    CTRL_MODE = 10
    Damp = 11
    Inertia = 12
    hw_ver = 13
    sw_ver = 14
    SN = 15
    NPP = 16
    Rs = 17
    LS = 18
    Flux = 19
    Gr = 20
    PMAX = 21
    VMAX = 22
    TMAX = 23
    I_BW = 24
    KP_ASR = 25
    KI_ASR = 26
    KP_APR = 27
    KI_APR = 28
    OV_Value = 29
    GREF = 30
    Deta = 31
    V_BW = 32
    IQ_c1 = 33
    VL_c1 = 34
    can_br = 35
    sub_ver = 36
    u_off = 50
    v_off = 51
    k1 = 52
    k2 = 53
    m_off = 54
    dir = 55
    p_m = 80
    xout = 81

limit_param = [
    [12.566, 50, 5],   # DM3507         check 
    [12.5, 30, 10],   # DM4310          check
    [12.5, 50, 10],   # DM4310_48V
    [12.5, 10, 28],   # DM4340          check
    [12.5, 20, 28],   # DM4340_48V      check
    [12.5, 45, 12],   # DM6006          check
    [12.566, 20, 120],   # DM6248       check
    [12.5, 45, 20],   # DM8006          check
    [12.5, 45, 54],   # DM8009          check
    [12.5, 25, 200],  # DM10010L        check
    [12.5, 20, 200],  # DM10010         check
    [12.5, 280, 1],   # DMH3510         check
    [12.5, 45, 10],   # DMH6215
    [12.5, 2000, 2],    # DMS3519         check
    [12.5, 45, 10]    # DMG6220         check
]

class ValueUnion:
    def __init__(self):
        self.floatValue = 0.0
        self.intValue = 0  # 若以后用到，可扩展

class ValueType:
    def __init__(self):
        self.value = ValueUnion()
        self.isFloat = False

# 电机类
class Motor:
    def __init__(self, motor_type: DM_Motor_Type, ctrl_mode: Control_Mode, can_id: int, master_id: int):
        self.Motor_Type = motor_type
        self.mode = ctrl_mode
        self.Can_id = can_id
        self.Master_id = master_id
        self.state_q = 0
        self.state_dq = 0
        self.state_tau = 0
        if motor_type.value < len(limit_param):
            self.limit_param = limit_param[motor_type.value]
        else:
            raise ValueError(f"Invalid motor type: {motor_type}")
        self.param_map: dict[int, ValueType] = {}
        self.last_time_ = time.monotonic()
        self.delta_time_= 0

    def updateTimeInterval(self) -> float:
        now = time.monotonic()
        self.delta_time_ = now - self.last_time_
        self.last_time_ = now
        return self.delta_time_  # 单位为秒
    
    def getTimeInterval(self): 
        return self.delta_time_


    def receive_data(self, q: float, dq: float, tau: float):
        self.state_q = q
        self.state_dq = dq
        self.state_tau = tau

    def set_param(self, key: int, value):
        v = ValueType()
        if type(value) is int:
            v.value.uint32Value = value
            v.isFloat = False
        elif type(value) is float:
            v.value.floatValue = value
            v.isFloat = True
        self.param_map[key] = v

    def get_param_as_float(self, key: int) -> float:
        v = self.param_map.get(key)
        if v is not None:
            if v.isFloat:
                return v.value.floatValue
        return 0.0

    def get_param_as_uint32(self, key: int) -> int:
        v = self.param_map.get(key)
        if v is not None:
            if not v.isFloat:
                return v.value.uint32Value
        return 0
    
    def is_have_param(self, key: int) -> bool:
        return key in self.param_map

    def GetMotorType(self):
        return self.Motor_Type
    def GetMotorMode(self):
        return self.mode   

    def get_limit_param(self):
        return self.limit_param  # 获取电机限制参数   

    def GetMasterId(self):
        return self.Master_id  # 获取反馈ID    

    def GetCanId(self):
        return self.Can_id  # 获取电机CAN ID

    def Get_Position(self):
        return self.state_q

    def Get_Velocity(self):
        return self.state_dq

    def Get_tau(self):
        return self.state_tau

    def set_mode(self, value: Control_Mode):
        self.mode = value

class Motor_Control:
    def __init__(self, nom_baud: int, dat_baud: int, sn: str , data_ptr: list):
        self.data_ptr_ = data_ptr
        self.motors: dict[int, Motor] = {}
        self.read_write_save = threading.Event()# 初始为未设置状态
        self.read_write_save.clear()
        
        # 遍历该bus下所有电机
        for act_data in self.data_ptr_:
            motor = Motor(act_data.motorType, act_data.mode, act_data.can_id, act_data.mst_id)
            self.addMotor(motor)

        self.usb_hw = usb_class(nom_baud, dat_baud,sn)
        time.sleep(0.5)

        self.usb_hw.setFrameCallback(lambda val: self.canframeCallback(val))
        time.sleep(0.2)

        self.enable_all()  # 使能该接口下的所有电机
        print("**********Motor_Control init success**********\n")

    # def __del__(self):
    #       print("Enter ~Motor_Control")
    #       if self.getUSBHw().getDeviceHandle() is not None:
    #           self.disable_all()  # 使能该接口下的所有电机
    #           self.usb_hw.close()
     
    def __enter__(self):
        # 必须返回 self 才能赋值给 usb2
        print("__enter__  Motor_Control")
        return self

    def __exit__(self, exc_type, exc_val, exc_tb):
        print("__exit__  Motor_Control")
        if self.getUSBHw().getDeviceHandle() is not None:
            self.disable_all()  # 失能该接口下的所有电机
            self.usb_hw.close()

    def close(self):
        print("close  Motor_Control")
        if self.getUSBHw().getDeviceHandle() is not None:
            self.disable_all()  # 使能该接口下的所有电机
            self.usb_hw.close()

    @staticmethod
    def is_in_ranges(number: int) -> bool:
        return (7 <= number <= 10) or (13 <= number <= 16) or (35 <= number <= 36)

    @staticmethod
    def float_to_uint32(value: float) -> int:
        return int(value)

    @staticmethod
    def uint32_to_float(value: int) -> float:
        return float(value)

    @staticmethod
    def uint8_to_float(data: List[int]) -> float:
        """
        参数 `data` 应为长度为 4 的整数列表（0-255）。
        例如：data = [0xDB, 0x0F, 0x49, 0x40] 表示 float 3.1415927
        """
        if len(data) != 4:
            raise ValueError("data must be a list of 4 bytes")
        byte_data = bytes(data)
        return struct.unpack('<f', byte_data)[0]
    
    def getMotor(self, id: int) -> Optional[Motor]:
        motor = self.motors.get(id)
        if motor is not None:
            return motor
        else:
            print(f"[Error] In getMotor, no motor with id {id} is registered.")
            return None

    def getUSBHw(self) -> Optional[usb_class]:
        return self.usb_hw
    
    def addMotor(self, DM_Motor:Motor):
        self.motors[DM_Motor.GetCanId()] = DM_Motor
        self.motors[DM_Motor.GetMasterId()] = DM_Motor

    def enable_all(self):
        # data=[4,0,0,0]
        # for motor in self.motors.values():
        #         for _ in range(5):
        #             self.write_motor_param(motor,0x23,data)
        #             time.sleep(0.002)  # 2000 microseconds = 2 milliseconds
        #             self.write_motor_param(motor,0x23,data)
        #             time.sleep(0.002)
        # for motor in self.motors.values():
        #     self.read_motor_param(motor,10)
        # for motor in self.motors.values():
        #     parm=motor.get_param_as_uint32(10)
        #     print(f"id: {motor.GetCanId()} mode is {parm}", file=sys.stderr)

        # for motor in self.motors.values():
        #     self.switchControlMode(motor,Control_Mode_Code.MIT)
        # for motor in self.motors.values():
        #     self.read_motor_param(motor,10)
        # for motor in self.motors.values():
        #     parm=motor.get_param_as_uint32(10)
        #     print(f"id: {motor.GetCanId()} mode is {parm}", file=sys.stderr)

        for motor in self.motors.values():
            self.switchControlMode(motor,Control_Mode_Code.MIT)
        for motor in self.motors.values():
            self.read_motor_param(motor,10)
        for motor in self.motors.values():
            parm=motor.get_param_as_uint32(10)
            print(f"id: {motor.GetCanId()} mode is {parm}", file=sys.stderr)

        for motor in self.motors.values():
            for _ in range(5):
                self.control_cmd(motor.GetCanId() + motor.GetMotorMode(), 0xFC)
                time.sleep(0.002)  

    def disable_all(self):
        for key, motor in self.motors.items():  # motors 是一个字典
            for _ in range(5):
                self.control_cmd(motor.GetCanId() + motor.GetMotorMode(), 0xFD)
                time.sleep(0.002)  # 2000 微秒 = 2 毫秒

    def read_motor_param(self, DM_Motor, RID: int) -> float:
        self.read_write_save.set()  # 表示正在进行参数读取

        can_id = DM_Motor.GetCanId()
        id_low = can_id & 0xFF
        id_high = (can_id >> 8) & 0xFF

        mydata = bytes([id_low, id_high, 0x33, RID, 0x00, 0x00, 0x00, 0x00])
        self.usb_hw.fdcanFrameSend(mydata, 0x7FF)
        time.sleep(0.002)
        return 0.0

    def save_motor_param(self, DM_Motor):
        id = DM_Motor.GetCanId()
        mode = DM_Motor.GetMotorMode()
        self.control_cmd(id + mode, 0xFD)  # 失能
        time.sleep(0.01)  # 10000 微秒 = 10 毫秒

        self.read_write_save.set()  # 标志位

        id_low = id & 0xFF
        id_high = (id >> 8) & 0xFF

        mydata = bytes([id_low, id_high, 0xAA, 0x01, 0x00, 0x00, 0x00, 0x00])
        self.usb_hw.fdcanFrameSend(mydata, 0x7FF)

        time.sleep(0.1)  # 100000 微秒 = 100 毫秒

    def refresh_motor_status(self, motor):
        id_low = motor.GetCanId() & 0xFF
        id_high = (motor.GetCanId() >> 8) & 0xFF

        mydata = bytes([id_low, id_high, 0xCC, 0x00])
        self.usb_hw.fdcanFrameSend(mydata, 0x7FF)

    def control_cmd(self, id: int, cmd: int):
        mydata = bytes([0xFF] * 7 + [cmd])
        self.usb_hw.fdcanFrameSend(mydata, id)

    def write_motor_param(self, DM_Motor, RID: int, data: list):
        self.read_write_save.set()

        id = DM_Motor.GetCanId()
        id_low = id & 0xFF
        id_high = (id >> 8) & 0xFF

        mydata = bytes([id_low, id_high, 0x55, RID, data[0], data[1], data[2], data[3]])
        self.usb_hw.fdcanFrameSend(mydata, 0x7FF)
        time.sleep(0.002)

    def set_zero_position(self, DM_Motor):
        self.control_cmd(DM_Motor.GetCanId() + DM_Motor.GetMotorMode(), 0xFE)
        time.sleep(0.002)

    def control_mit(self, DM_Motor, kp: float, kd: float, q: float, dq: float, tau: float):
        float_to_uint = lambda x, xmin, xmax, bits: int((x - xmin) / (xmax - xmin) * ((1 << bits) - 1))

        id = DM_Motor.GetCanId()
        if id not in self.motors:
            print(f"[Error] In control_mit, no motor with id {DM_Motor.GetCanId()} is registered.")
            sys.exit(-1)

        m = self.motors[id]
        kp_uint = float_to_uint(kp, 0, 500, 12)
        kd_uint = float_to_uint(kd, 0, 5, 12)

        limit_param_cmd = m.get_limit_param()

        q_uint = float_to_uint(q, -limit_param_cmd[0], limit_param_cmd[0], 16)
        dq_uint = float_to_uint(dq, -limit_param_cmd[1], limit_param_cmd[1], 12)
        tau_uint = float_to_uint(tau, -limit_param_cmd[2], limit_param_cmd[2], 12)

        can_id = id + Control_Mode.MIT_MODE

        data = [0] * 8
        data[0] = (q_uint >> 8) & 0xff
        data[1] = q_uint & 0xff
        data[2] = dq_uint >> 4
        data[3] = ((dq_uint & 0xf) << 4) | ((kp_uint >> 8) & 0xf)
        data[4] = kp_uint & 0xff
        data[5] = kd_uint >> 4
        data[6] = ((kd_uint & 0xf) << 4) | ((tau_uint >> 8) & 0xf)
        data[7] = tau_uint & 0xff

        self.usb_hw.fdcanFrameSend(data, can_id)

    def control_pos_vel(self, DM_Motor, pos: float, vel: float):
        id_ = DM_Motor.GetCanId()
        if id_ not in self.motors:
            print(f"[Error] In control_pos_vel, no motor with id {id_} is registered.", file=sys.stderr)
            sys.exit(-1)  # 终止程序，返回非 0 表示错误

        can_id = id_ + Control_Mode.POS_VEL_MODE  # 需要保证 self.POS_VEL_MODE 定义了

        # 把 float 按 4 字节小端序转换为 bytes
        pbuf = struct.pack('<f', pos)
        vbuf = struct.pack('<f', vel)

        # 组合数据成长度8的list
        mydata = list(pbuf + vbuf)  # bytes 拼接后转成列表

        self.usb_hw.fdcanFrameSend(mydata, can_id)

    def control_vel(self, DM_Motor, vel: float):
        id_ = DM_Motor.GetCanId()
        if id_ not in self.motors:
            print(f"[Error] In control_vel, no motor with id {id_} is registered.", file=sys.stderr)
            sys.exit(-1)

        can_id = id_ + Control_Mode.VEL_MODE

        # 把 float 按 4 字节小端序转换成 bytes
        vbuf = struct.pack('<f', vel)

        # 只取4个字节，转换成列表
        mydata = list(vbuf)

        self.usb_hw.fdcanFrameSend(mydata, can_id)

    # def receive_param(self, data: bytes):
    #     canID = (data[1] << 8) | data[0]
    #     RID = data[3]
    #     if canID not in self.motors:
    #         print(f"[Error] In receive_param, no motor with id {canID} is registered.", file=sys.stderr)
    #         sys.exit(-1)

    #     if self.is_in_ranges(RID):
    #         data_uint32 = (data[7] << 24) | (data[6] << 16) | (data[5] << 8) | data[4]
    #         self.motors[canID].set_param(RID, data_uint32)

    #         if RID == 10:
    #             if data_uint32 == 1:
    #                 self.motors[canID].set_mode(Control_Mode.MIT_MODE)
    #             elif data_uint32 == 2:
    #                 self.motors[canID].set_mode(Control_Mode.POS_VEL_MODE)
    #             elif data_uint32 == 3:
    #                 self.motors[canID].set_mode(Control_Mode.VEL_MODE)
    #             elif data_uint32 == 4:
    #                 self.motors[canID].set_mode(Control_Mode.POS_FORCE_MODE)
    #     else:
    #         data_float = self.uint8_to_float(data[4:8])  # 取4个字节，转float
    #         self.motors[canID].set_param(RID, data_float)

    # 在 damiao.py 中修改 receive_param 方法
    def receive_param(self, data: bytes):
        canID = (data[1] << 8) | data[0]
        RID = data[3]
        
        # 调试信息
        if canID >= 0x7D00:  # Master ID 范围
            # 尝试找到对应的 CAN ID
            found_can_id = None
            for motor_id, motor in self.motors.items():
                if motor.GetMasterId() == canID:
                    found_can_id = motor.GetCanId()
                    break
            
            if found_can_id is not None:
                canID = found_can_id
            else:
                # 如果没有找到，但 canID 是某个电机的 Master ID，我们仍然处理
                # 但需要确认这个 canID 是否在 motors 中
                if canID not in self.motors:
                    # 检查是否是某个电机的 Master ID
                    for motor in self.motors.values():
                        if motor.GetMasterId() == canID:
                            # 临时添加到 motors 字典，用 Master ID
                            self.motors[canID] = motor
                            break
                    else:
                        # 如果还不是，则忽略
                        print(f"[Warning] In receive_param, no motor with id {hex(canID)} is registered, ignoring. Data: {list(data)}", file=sys.stderr)
                        return
        
        if canID not in self.motors:
            print(f"[Error] In receive_param, no motor with id {hex(canID)} is registered.", file=sys.stderr)
            return  # 改为返回而不是退出

        m = self.motors[canID]
        
        if self.is_in_ranges(RID):
            data_uint32 = (data[7] << 24) | (data[6] << 16) | (data[5] << 8) | data[4]
            m.set_param(RID, data_uint32)

            if RID == 10:
                if data_uint32 == 1:
                    m.set_mode(Control_Mode.MIT_MODE)
                elif data_uint32 == 2:
                    m.set_mode(Control_Mode.POS_VEL_MODE)
                elif data_uint32 == 3:
                    m.set_mode(Control_Mode.VEL_MODE)
                elif data_uint32 == 4:
                    m.set_mode(Control_Mode.POS_FORCE_MODE)
        else:
            data_float = self.uint8_to_float(data[4:8])  # 取4个字节，转float
            m.set_param(RID, data_float)
        
    def switchControlMode(self, DM_Motor, mode:Control_Mode_Code):
        write_data = bytes([mode, 0x00, 0x00, 0x00])
        RID = 10
        self.write_motor_param(DM_Motor, RID, write_data)

        can_id = DM_Motor.GetCanId()
        if can_id not in self.motors:
            print(f"[Error] In switchControlMode, no motor with id {can_id} is registered.", file=sys.stderr)
            sys.exit(-1)
            return False

        return True

    def change_motor_param(self, DM_Motor, RID, data):
        if self.is_in_ranges(RID):
            # 传入的应转换为整型表示
            data_uint32 = self.float_to_uint32(data)
            data_bytes = data_uint32.to_bytes(4, byteorder='little')
            self.write_motor_param(DM_Motor, RID, data_bytes)
        else:
            data_bytes = struct.pack('f', data)
            self.write_motor_param(DM_Motor, RID, data_bytes)

        can_id = DM_Motor.GetCanId()
        if can_id not in self.motors:
            print(f"[Error] In change_motor_param, no motor with id {can_id} is registered.", file=sys.stderr)
            sys.exit(-1)
            return False

        return True

    def changeMotorLimit(self, DM_Motor, P_MAX, Q_MAX, T_MAX):
        motor_type = DM_Motor.GetMotorType()
        self.limit_param[motor_type] = [P_MAX, Q_MAX, T_MAX]

    """ 
    can_value_type在usb_class类里面是这样定义的
        class can_head_type:
            def __init__(self):
                self.id = 0
                self.time_stamp = 0
                self.reserve = [0, 0, 0]
                self.fram_type = 0
                self.can_type = 0
                self.id_type = 0
                self.dir = 0
                self.dlc = 0  

        class can_value_type:
            def __init__(self):
                self.head = can_head_type()
                self.data = [0] * 64
    """
    def canframeCallback(self, value:can_value_type):
        uint_to_float = lambda x, xmin, xmax, bits: ((float(x) / ((1 << bits) - 1)) * (xmax - xmin)) + xmin

        canID = value.head.id

        if self.read_write_save.is_set() and canID in self.motors:
            if value.data[2] in (0x33, 0x55, 0xAA):
                if value.data[2] in (0x33, 0x55):
                    #print(value.data[4])
                    self.receive_param(bytes(value.data))
                    self.read_write_save.clear()
                self.read_write_save.clear()
        else:
            q_uint = (value.data[1] << 8) | value.data[2]
            dq_uint = (value.data[3] << 4) | (value.data[4] >> 4)
            tau_uint = ((value.data[4] & 0xf) << 8) | value.data[5]

            if canID not in self.motors:
                return

            m = self.motors[canID]
            limit_param_receive = m.get_limit_param()
            receive_q = uint_to_float(q_uint, -limit_param_receive[0], limit_param_receive[0], 16)
            receive_dq = uint_to_float(dq_uint, -limit_param_receive[1], limit_param_receive[1], 12)
            receive_tau = uint_to_float(tau_uint, -limit_param_receive[2], limit_param_receive[2], 12)

            m.receive_data(receive_q, receive_dq, receive_tau)

            interval=m.updateTimeInterval()
            
            #print(f"motor id is: {canID}: {interval}", file=sys.stderr)
            
            
           
running =threading.Event()
running.set()  # 初始为 True

# Ctrl+C 信号处理函数
def signal_handler(signum, frame):
    running.clear()
    sys.stderr.write(f"\nInterrupt signal ({signum}) received.\n")
    sys.stderr.flush()



running =threading.Event()
running.set()  # 初始为 True

# Ctrl+C 信号处理函数
def signal_handler(signum, frame):
    running.clear()
    sys.stderr.write(f"\nInterrupt signal ({signum}) received.\n")
    sys.stderr.flush()

# 注册 SIGINT 处理（即 Ctrl+C）
signal.signal(signal.SIGINT, signal_handler)
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

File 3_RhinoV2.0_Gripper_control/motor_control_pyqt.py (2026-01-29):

#!/usr/bin/env python3
# -*- coding: utf-8 -*-
"""
电机控制UI界面 - PyQt5版本
提供打开和闭合两个按钮，可设定力矩值
"""

import sys
import time
import signal
from PyQt5.QtWidgets import (QApplication, QMainWindow, QWidget, QVBoxLayout,
                             QHBoxLayout, QLabel, QPushButton, QDoubleSpinBox,
                             QGroupBox, QMessageBox, QFrame)
from PyQt5.QtCore import QThread, pyqtSignal, Qt, QTimer
from PyQt5.QtGui import QFont, QPalette, QColor
from damiao import *

# 全局应用实例
app_instance = None


class MotorControlThread(QThread):
    """电机控制线程"""
    error_signal = pyqtSignal(str)

    def __init__(self, control, canid):
        super().__init__()
        self.control = control
        self.canid = canid
        self.torque = 0.0
        self.running = True

    def set_torque(self, torque):
        """设置力矩值（实时生效）"""
        self.torque = torque

    def run(self):
        """运行电机控制循环"""
        try:
            while self.running:
                if self.control is not None:
                    self.control.control_mit(self.control.getMotor(self.canid),
                                           0.0, 0.0, 0.0, 0.0, self.torque)
                time.sleep(0.01)  # 10ms控制周期
        except Exception as e:
            self.error_signal.emit(f"电机控制错误: {e}")
        finally:
            # 停止电机
            if self.control is not None:
                try:
                    self.control.control_mit(self.control.getMotor(self.canid),
                                           0.0, 0.0, 0.0, 0.0, 0.0)
                except:
                    pass

    def stop(self):
        """停止线程"""
        self.running = False


class MotorControlUI(QMainWindow):
    def __init__(self):
        super().__init__()

        # 电机控制相关
        self.control = None
        self.canid = 0x01
        self.mstid = 0x11
        self.motor_thread = None
        self.current_mode = None
        self.motor_enabled = False  # 电机使能状态

        # 默认力矩值
        self.open_torque_value = -0.25
        self.close_torque_value = 0.15

        # 初始化UI
        self.init_ui()

        # 延迟初始化电机（让UI先显示）
        QTimer.singleShot(100, self.init_motor)

    def init_ui(self):
        """初始化UI"""
        self.setWindowTitle("电机控制系统")
        self.setGeometry(100, 100, 600, 500)

        # 设置样式
        self.setStyleSheet("""
            QMainWindow {
                background-color: #f5f5f5;
            }
            QGroupBox {
                font-size: 14px;
                font-weight: bold;
                border: 2px solid #cccccc;
                border-radius: 8px;
                margin-top: 10px;
                padding-top: 10px;
                background-color: white;
            }
            QGroupBox::title {
                subcontrol-origin: margin;
                left: 10px;
                padding: 0 5px;
            }
            QPushButton {
                font-size: 16px;
                font-weight: bold;
                border-radius: 8px;
                padding: 15px;
                min-height: 60px;
            }
            QPushButton:hover {
                opacity: 0.8;
            }
            QPushButton:disabled {
                background-color: #cccccc;
                color: #666666;
            }
            QLabel {
                font-size: 13px;
            }
            QDoubleSpinBox {
                font-size: 14px;
                padding: 5px;
                border: 2px solid #cccccc;
                border-radius: 4px;
                min-height: 30px;
            }
        """)

        # 中心部件
        central_widget = QWidget()
        self.setCentralWidget(central_widget)
        main_layout = QVBoxLayout(central_widget)
        main_layout.setSpacing(20)
        main_layout.setContentsMargins(30, 30, 30, 30)

        # 标题
        title_label = QLabel("电机控制系统")
        title_font = QFont("Arial", 24, QFont.Bold)
        title_label.setFont(title_font)
        title_label.setAlignment(Qt.AlignCenter)
        title_label.setStyleSheet("color: #333333; margin-bottom: 10px;")
        main_layout.addWidget(title_label)

        # 状态信息组
        status_group = QGroupBox("状态信息")
        status_layout = QVBoxLayout()
        status_layout.setSpacing(10)

        self.status_label = QLabel("电机状态: 初始化中...")
        self.status_label.setAlignment(Qt.AlignCenter)
        self.status_label.setStyleSheet("font-size: 14px; color: #666666;")
        status_layout.addWidget(self.status_label)

        self.mode_label = QLabel("当前模式: 无")
        self.mode_label.setAlignment(Qt.AlignCenter)
        self.mode_label.setStyleSheet("font-size: 14px; color: #666666;")
        status_layout.addWidget(self.mode_label)

        status_group.setLayout(status_layout)
        main_layout.addWidget(status_group)

        # 电机使能/失能区域
        enable_layout = QHBoxLayout()
        enable_layout.setSpacing(10)

        self.enable_button = QPushButton("使能电机")
        self.enable_button.setStyleSheet("""
            QPushButton {
                background-color: #FF9800;
                color: white;
                min-height: 40px;
            }
            QPushButton:hover {
                background-color: #F57C00;
            }
        """)
        self.enable_button.clicked.connect(self.enable_motor)
        self.enable_button.setEnabled(False)
        enable_layout.addWidget(self.enable_button)

        self.disable_button = QPushButton("失能电机")
        self.disable_button.setStyleSheet("""
            QPushButton {
                background-color: #9E9E9E;
                color: white;
                min-height: 40px;
            }
            QPushButton:hover {
                background-color: #757575;
            }
        """)
        self.disable_button.clicked.connect(self.disable_motor)
        self.disable_button.setEnabled(False)
        enable_layout.addWidget(self.disable_button)

        main_layout.addLayout(enable_layout)

        # 控制按钮区域
        control_layout = QHBoxLayout()
        control_layout.setSpacing(20)

        # 打开控制组
        open_group = QGroupBox("打开")
        open_layout = QVBoxLayout()
        open_layout.setSpacing(10)

        open_torque_label = QLabel("力矩值:")
        open_torque_label.setAlignment(Qt.AlignCenter)
        open_layout.addWidget(open_torque_label)

        self.open_torque_spin = QDoubleSpinBox()
        self.open_torque_spin.setRange(-10.0, 0.0)
        self.open_torque_spin.setSingleStep(0.1)
        self.open_torque_spin.setValue(self.open_torque_value)
        self.open_torque_spin.setDecimals(2)
        self.open_torque_spin.setSuffix(" N·m")
        self.open_torque_spin.setAlignment(Qt.AlignCenter)
        self.open_torque_spin.valueChanged.connect(self.on_open_torque_changed)
        open_layout.addWidget(self.open_torque_spin)
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

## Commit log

2026-01-26 update file name
    [BOM.xlsx, 丝杆.SLDDRW, 丝杆.STEP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]
2026-01-29 update gripper_control
2026-02-03 update BOM
    [BOM.xlsx]
2026-02-27 修改丝杆螺丝底孔直径6->7 添加丝杆和螺母pdf
    [丝杆螺母.SLDDRW, 丝杆螺母.SLDPRT]
